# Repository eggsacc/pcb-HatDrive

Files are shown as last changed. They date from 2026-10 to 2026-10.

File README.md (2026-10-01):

# BLDC Hat






A four-layer BLDC motor driver hat built around the TI DRV8316C for the [STM32F405 development module](https://github.com/eggsacc/stm32f405-module). It is intended for six-PWM motor control and field-oriented control experiments.

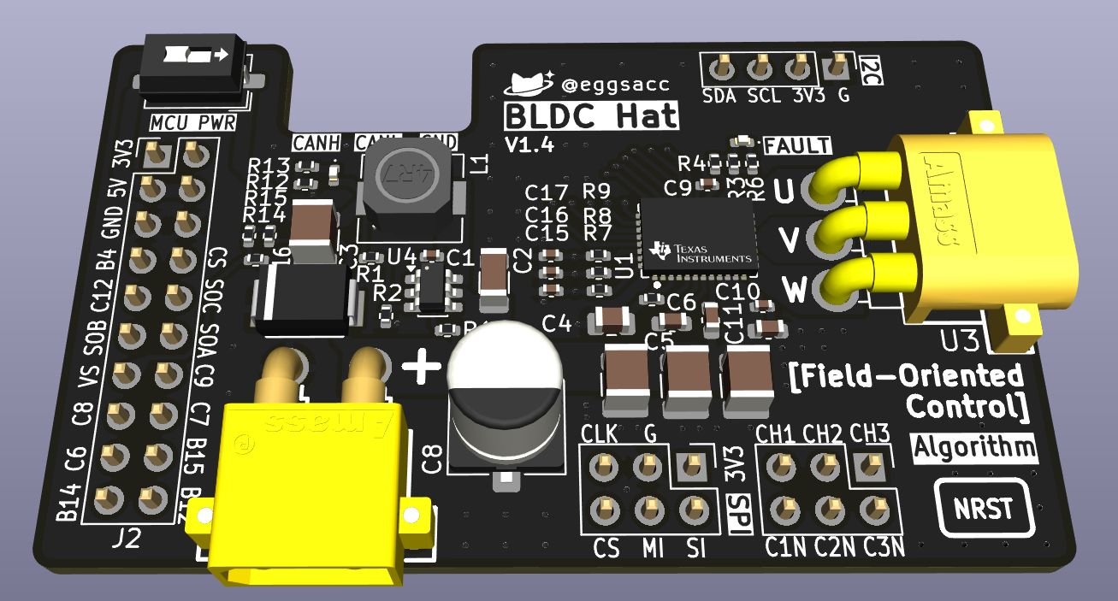
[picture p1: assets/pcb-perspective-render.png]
BLDC Hat perspective render


## Hardware

- Three-phase driver with six PWM inputs, three low-side current-sense outputs, SPI configuration/status, and motor-supply voltage sensing.
- Onboard 5 V buck converter with a switch for MCU power, plus power and fault LEDs.
- Four-layer PCB; board revision V1.4.

## Connectors

| Connector | Purpose |
| --- | --- |
| CN1 · XT30 | Motor power input (`VM_IN`) |
| U3 · MR30 | Three motor phases (`U`, `V`, `W`) |
| J2 · 2×10 | Interface to the STM32F405 module |
| J4 · 2×3 | Six PWM inputs (`CH1–3`, `C1N–3N`) |
| J1 · 2×3 | Driver SPI (`CLK`, `CS`, `MI`, `SI`, 3V3, GND) |
| J5 · 1×4 | I²C (`SDA`, `SCL`, 3V3, GND) |
| CN2 · XT30 | Optional motor-power output; marked DNP in the BOM |

With `MCU PWR` on, the hat supplies 5 V to the MCU module. Its [power guidance](https://github.com/eggsacc/stm32f405-module#power) warns against connecting USB and external 5 V at the same time.

## Layout
>L1: Power & signal

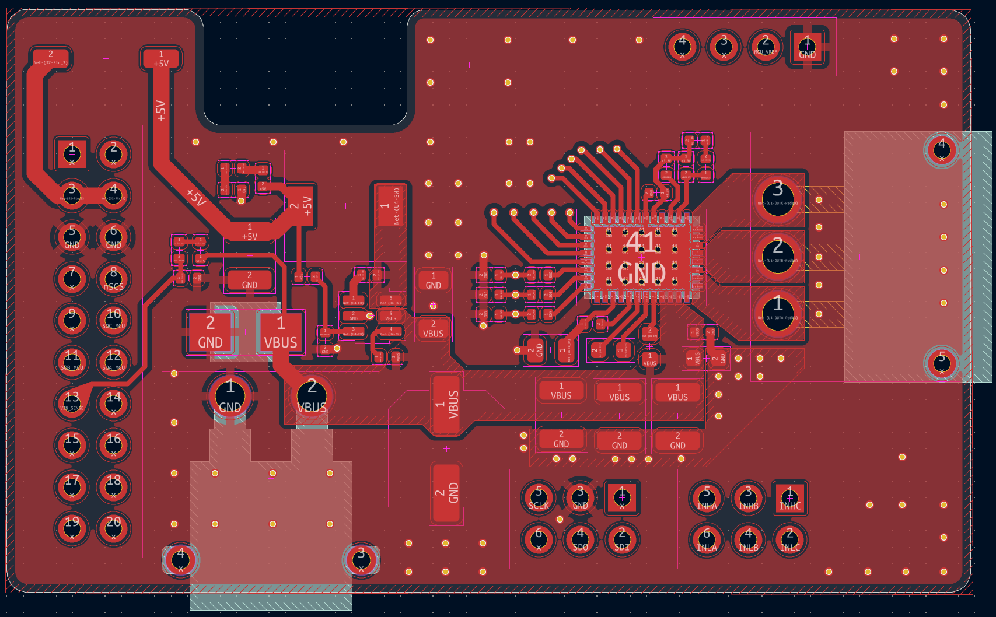
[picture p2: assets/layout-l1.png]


>L2: GND

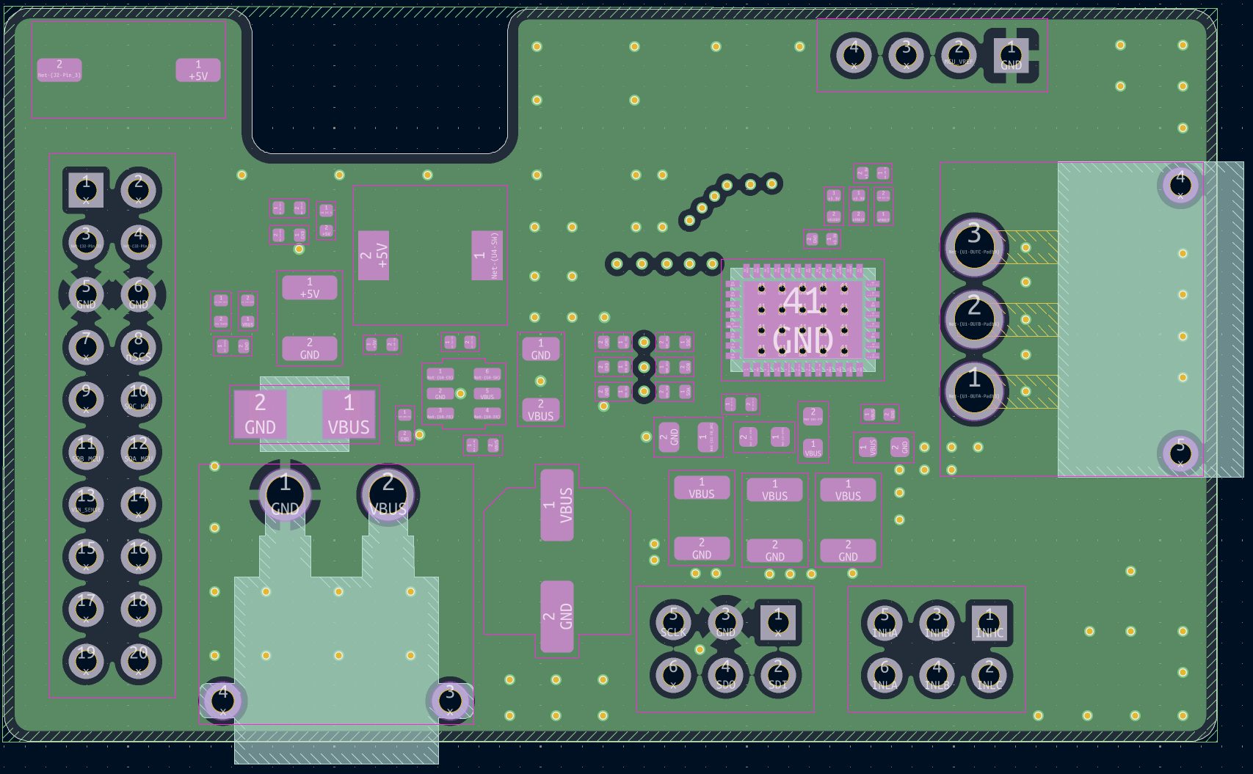
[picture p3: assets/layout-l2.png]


>L3: GND + PWM signal

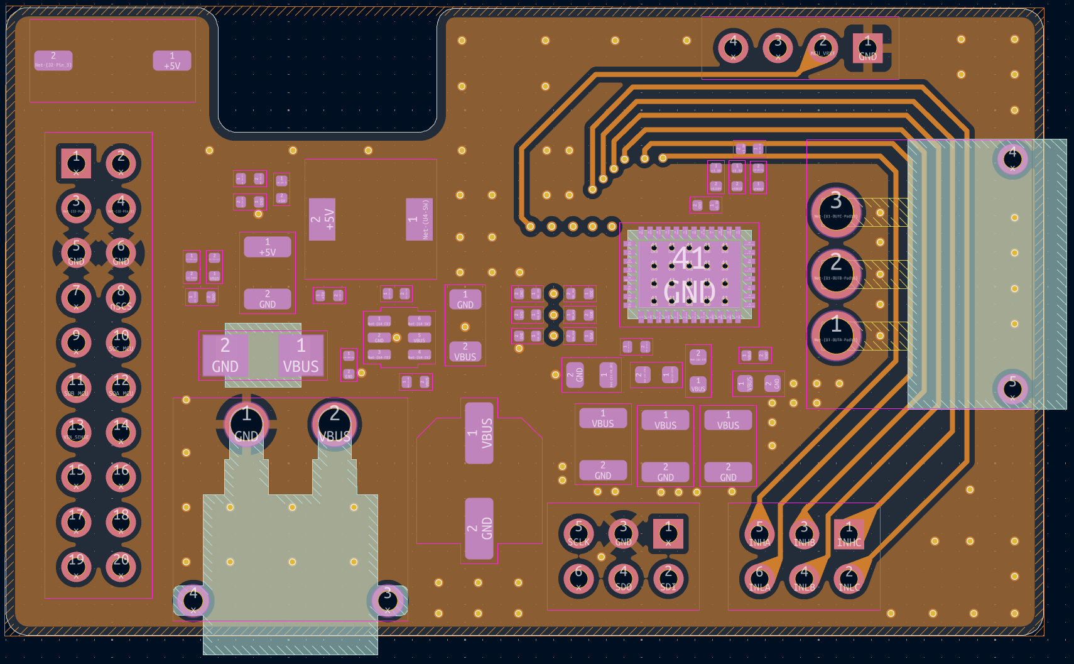
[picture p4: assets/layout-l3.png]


>L4: GND + signal

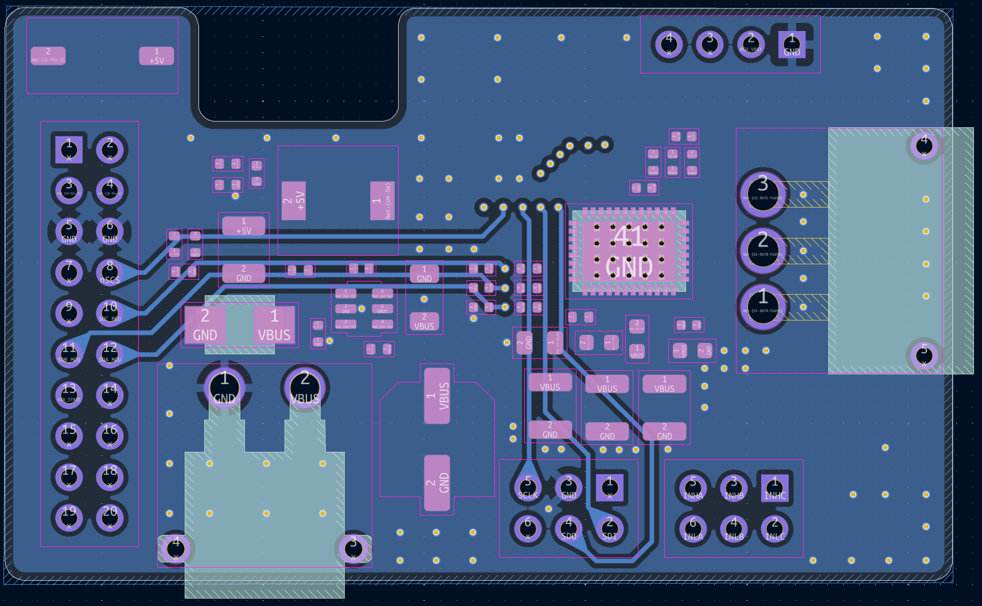
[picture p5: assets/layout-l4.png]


> Silkscreen
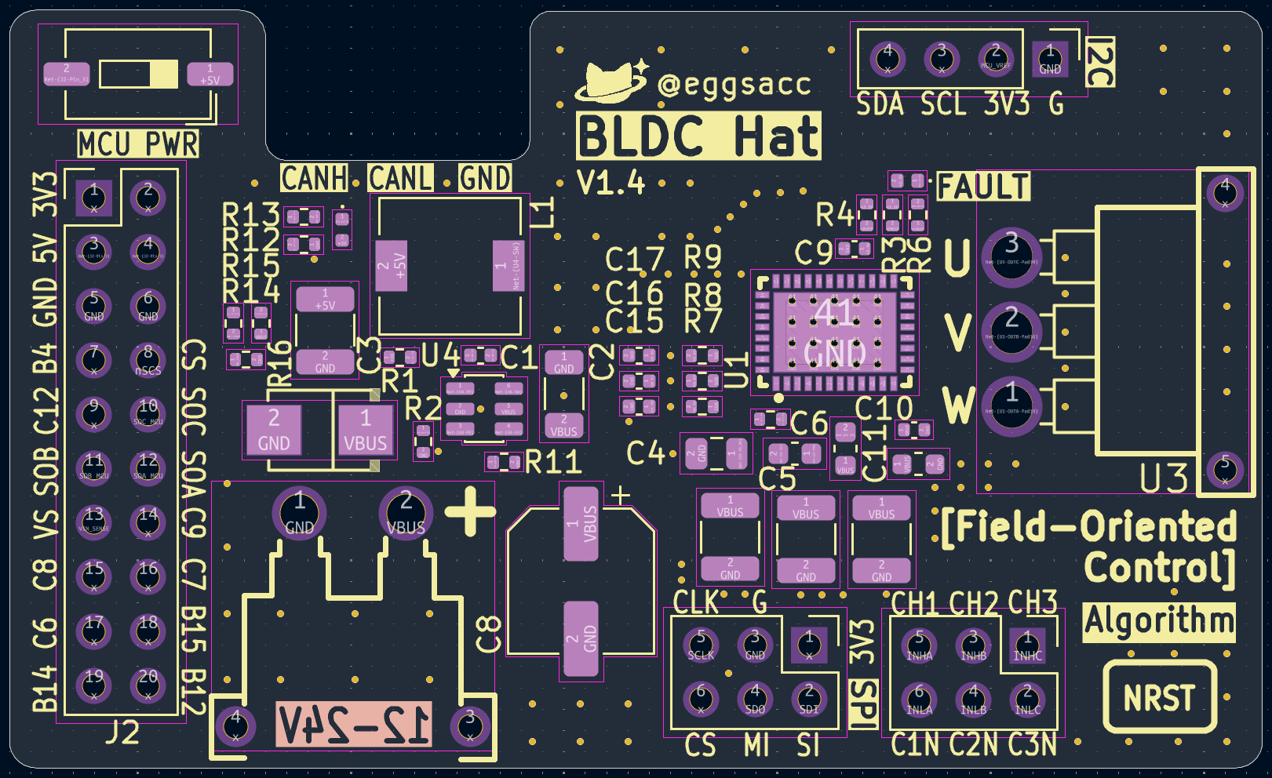
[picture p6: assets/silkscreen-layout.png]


>Combined
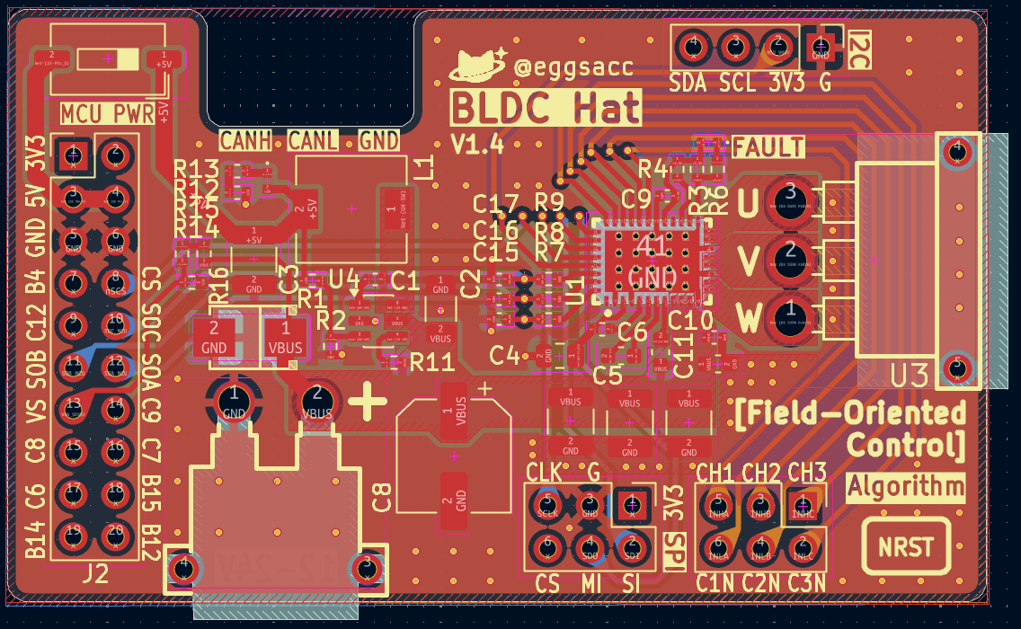
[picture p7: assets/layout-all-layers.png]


The [KiCad project](HatDrive_kicad/) contains the schematic, PCB, and manufacturing files. See the [MCU module README](https://github.com/eggsacc/stm32f405-module) for its pinout.

---

<div align="center">
Designed by <b>@eggsacc</b> · HatDrive V1.4 <br>
Updated 02/10/2026
</div>

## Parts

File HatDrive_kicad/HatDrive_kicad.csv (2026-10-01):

Reference | Qty | Value | DNP | Footprint | Purchased
C1,C10,C11,C12 | 4 | 100n |  | Capacitor_SMD:C_0402_1005Metric | TRUE
C2 | 1 | 2u2 |  | Capacitor_SMD:C_1206_3216Metric | TRUE
C3 | 1 | 22u |  | Capacitor_SMD:C_1210_3225Metric | TRUE
C4 | 1 | 22u |  | Capacitor_SMD:C_0805_2012Metric | TRUE
C5 | 1 | 47n |  | Capacitor_SMD:C_0603_1608Metric | TRUE
C6 | 1 | 1u |  | Capacitor_SMD:C_0603_1608Metric | TRUE
C8 | 1 | 47u |  | Capacitor_SMD:CP_Elec_6.3x7.7 | TRUE
C9 | 1 | 1u |  | Capacitor_SMD:C_0402_1005Metric | TRUE
C15,C16,C17 | 3 | 1n |  | Capacitor_SMD:C_0402_1005Metric | TRUE
C18,C19,C20 | 3 | 10u |  | Capacitor_SMD:C_1210_3225Metric | TRUE
CN1 | 1 | VM_IN |  | fplib_addon:CONN-TH_XT30PW-M | TRUE
CN2 | 1 | VM_OUT | DNP | fplib_addon:CONN-TH_XT30PW-M | TRUE
D1 | 1 | FAULT_LED |  | LED_SMD:LED_0402_1005Metric | TRUE
D2 | 1 | MCU_PWR_LED |  | LED_SMD:LED_0402_1005Metric | TRUE
D3 | 1 | SMBJ28AQ |  | fplib_addon:SMB_L4.3-W3.6-LS5.3-RD | TRUE
J1 | 1 | SPI |  | Connector_PinHeader_2.54mm:PinHeader_2x03_P2.54mm_Vertical | TRUE
J2 | 1 | Breakout header |  | Connector_PinHeader_2.54mm:PinHeader_2x10_P2.54mm_Vertical | TRUE
J4 | 1 | PWM |  | Connector_PinHeader_2.54mm:PinHeader_2x03_P2.54mm_Vertical | TRUE
J5 | 1 | I2C |  | Connector_PinHeader_2.54mm:PinHeader_1x04_P2.54mm_Vertical | TRUE
L1 | 1 | 33u |  | Inductor_SMD:L_6.3x6.3_H3 | TRUE
R1 | 1 | 118k |  | Resistor_SMD:R_0402_1005Metric | TRUE
R2,R14,R15 | 3 | 22k1 |  | Resistor_SMD:R_0402_1005Metric | TRUE
R3,R4,R5,R7,R8,R9,R11 | 7 | 10k |  | Resistor_SMD:R_0402_1005Metric | TRUE
R6,R12,R13 | 3 | 470 |  | Resistor_SMD:R_0402_1005Metric | TRUE
R10 | 1 | 22 |  | Resistor_SMD:R_0402_1005Metric | TRUE
R16 | 1 | 5k1 |  | Resistor_SMD:R_0402_1005Metric | TRUE
SW1 | 1 | MCU_POWER |  | Button_Switch_SMD:SW_DIP_SPSTx01_Slide_6.7x4.1mm_W6.73mm_P2.54mm_LowProfile_JPin | TRUE
U1 | 1 | DRV8316CRRGFR |  | fplib_addon:DRV8316CR | TRUE
U3 | 1 | Phase out |  | fplib_addon:CONN-TH_MR30PW-M30-G-Y | TRUE
U4 | 1 | LMR51610XDBVR |  | Package_TO_SOT_SMD:SOT-23-6 | TRUE

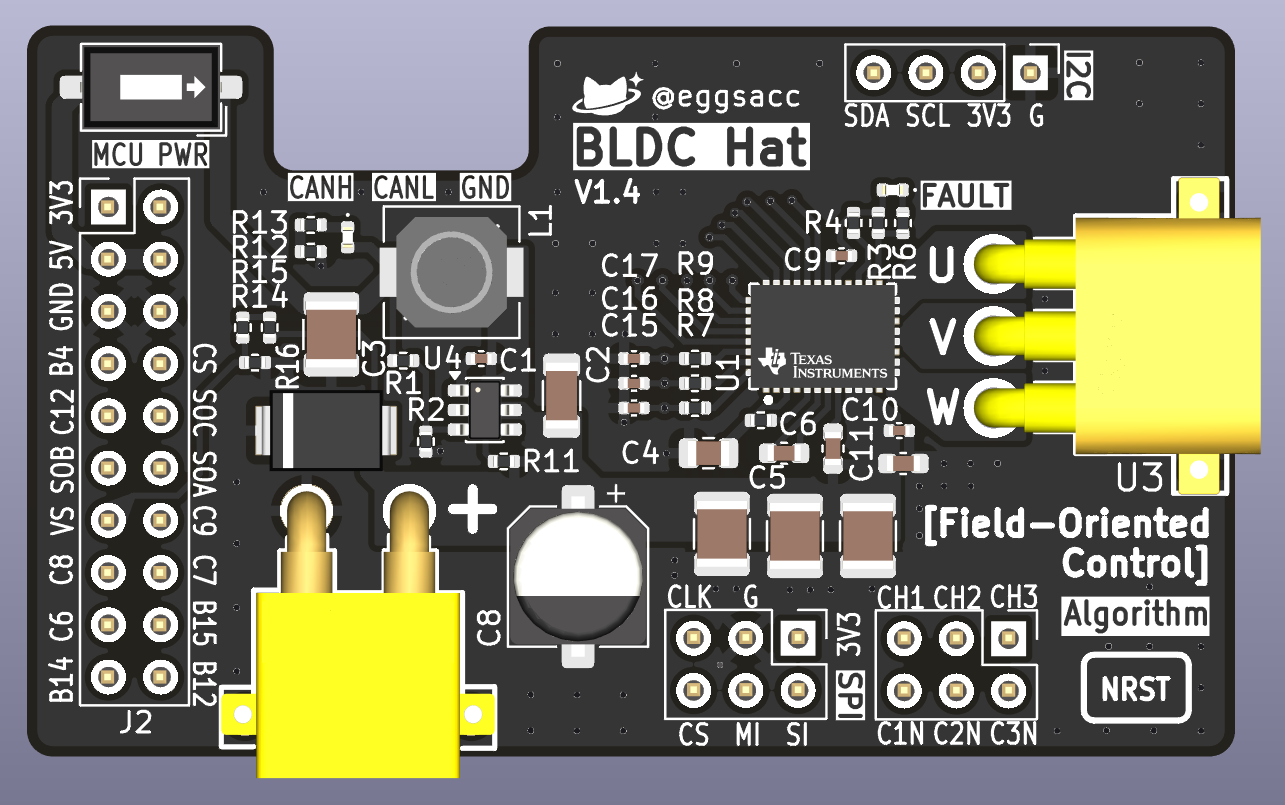
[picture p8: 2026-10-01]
assets/pcb-ortho-all-components.png

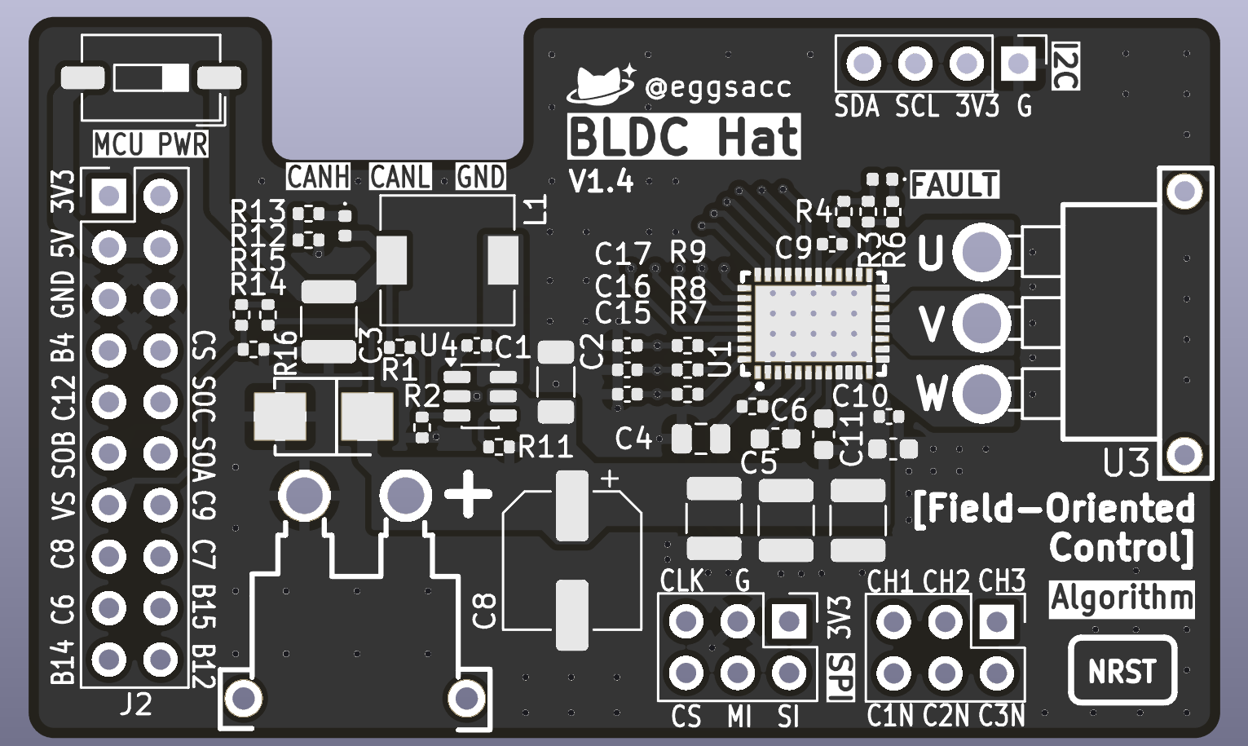
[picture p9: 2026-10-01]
assets/pcb-ortho-no-components.png

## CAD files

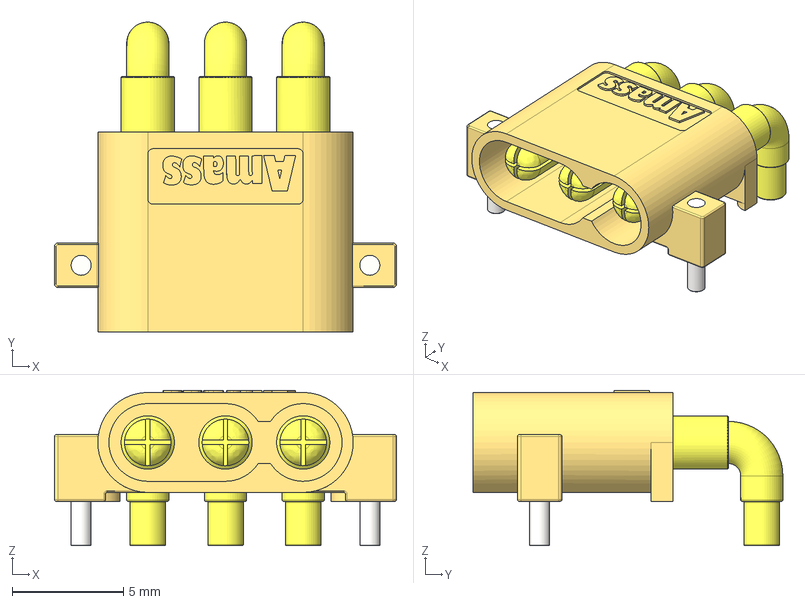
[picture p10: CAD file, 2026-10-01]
HatDrive_kicad/3d-models/MR30PW-M v2.step
15.4 x 13.9 x 7.00 mm
PCB Pins
Pin 2 x 3

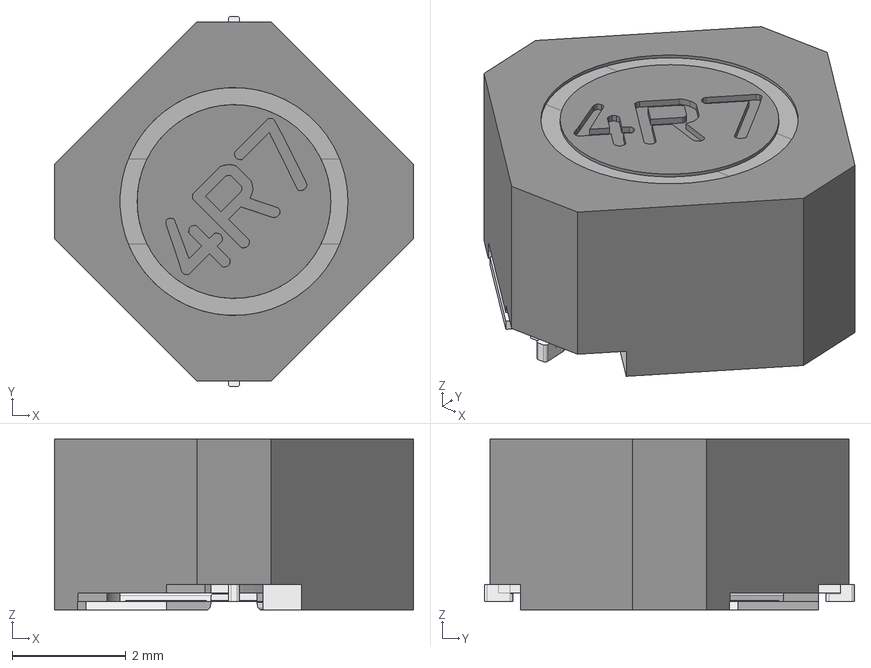
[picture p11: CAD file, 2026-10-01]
HatDrive_kicad/3d-models/Inductor_63.step
6.30 x 6.50 x 3.00 mm
Protection
Inner_Pins
Inductor_Core
Pins
Inductor_Case

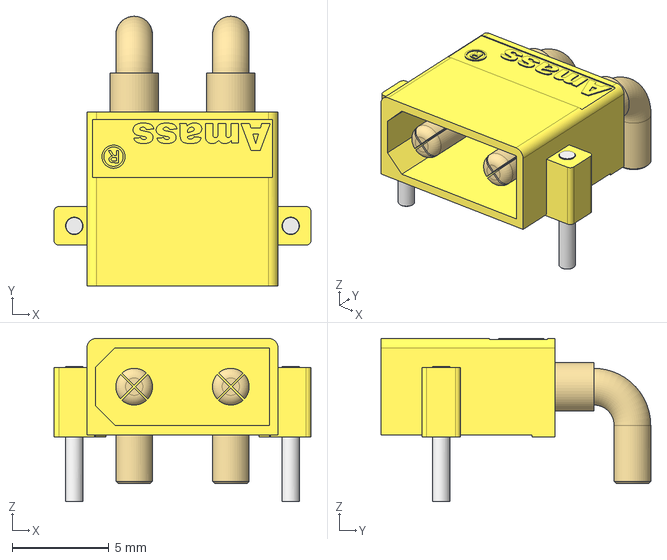
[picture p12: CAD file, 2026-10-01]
HatDrive_kicad/3d-models/Amass_XT30PW-M_pcb solder.stp
13.3 x 13.9 x 8.45 mm

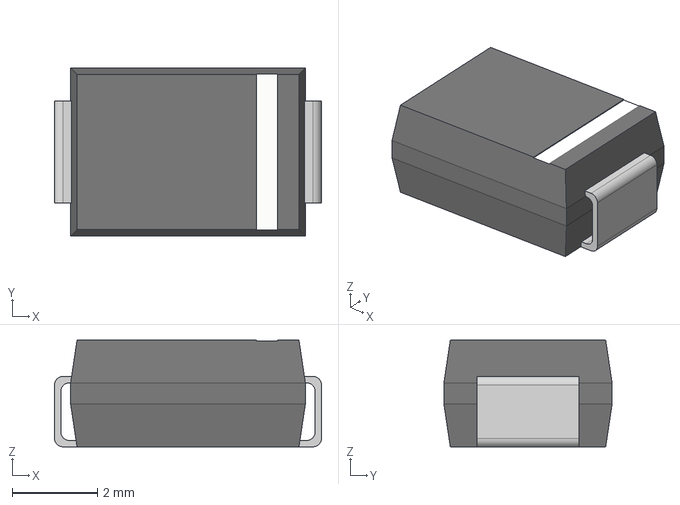
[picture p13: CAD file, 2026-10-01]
HatDrive_kicad/3d-models/smbj-28a.step
6.25 x 3.94 x 2.50 mm

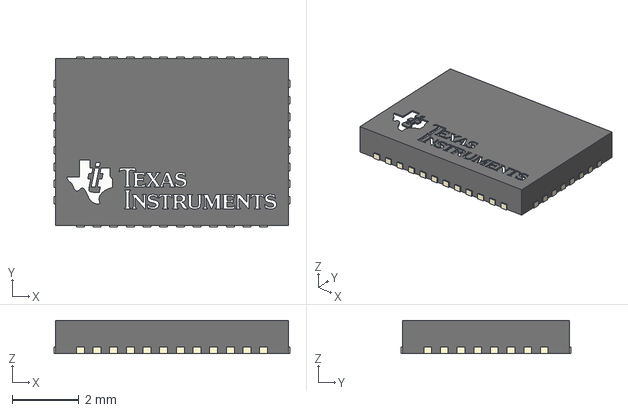
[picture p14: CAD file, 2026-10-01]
HatDrive_kicad/3d-models/VQFN40p-7x5-TI.step
7.08 x 5.09 x 1.00 mm

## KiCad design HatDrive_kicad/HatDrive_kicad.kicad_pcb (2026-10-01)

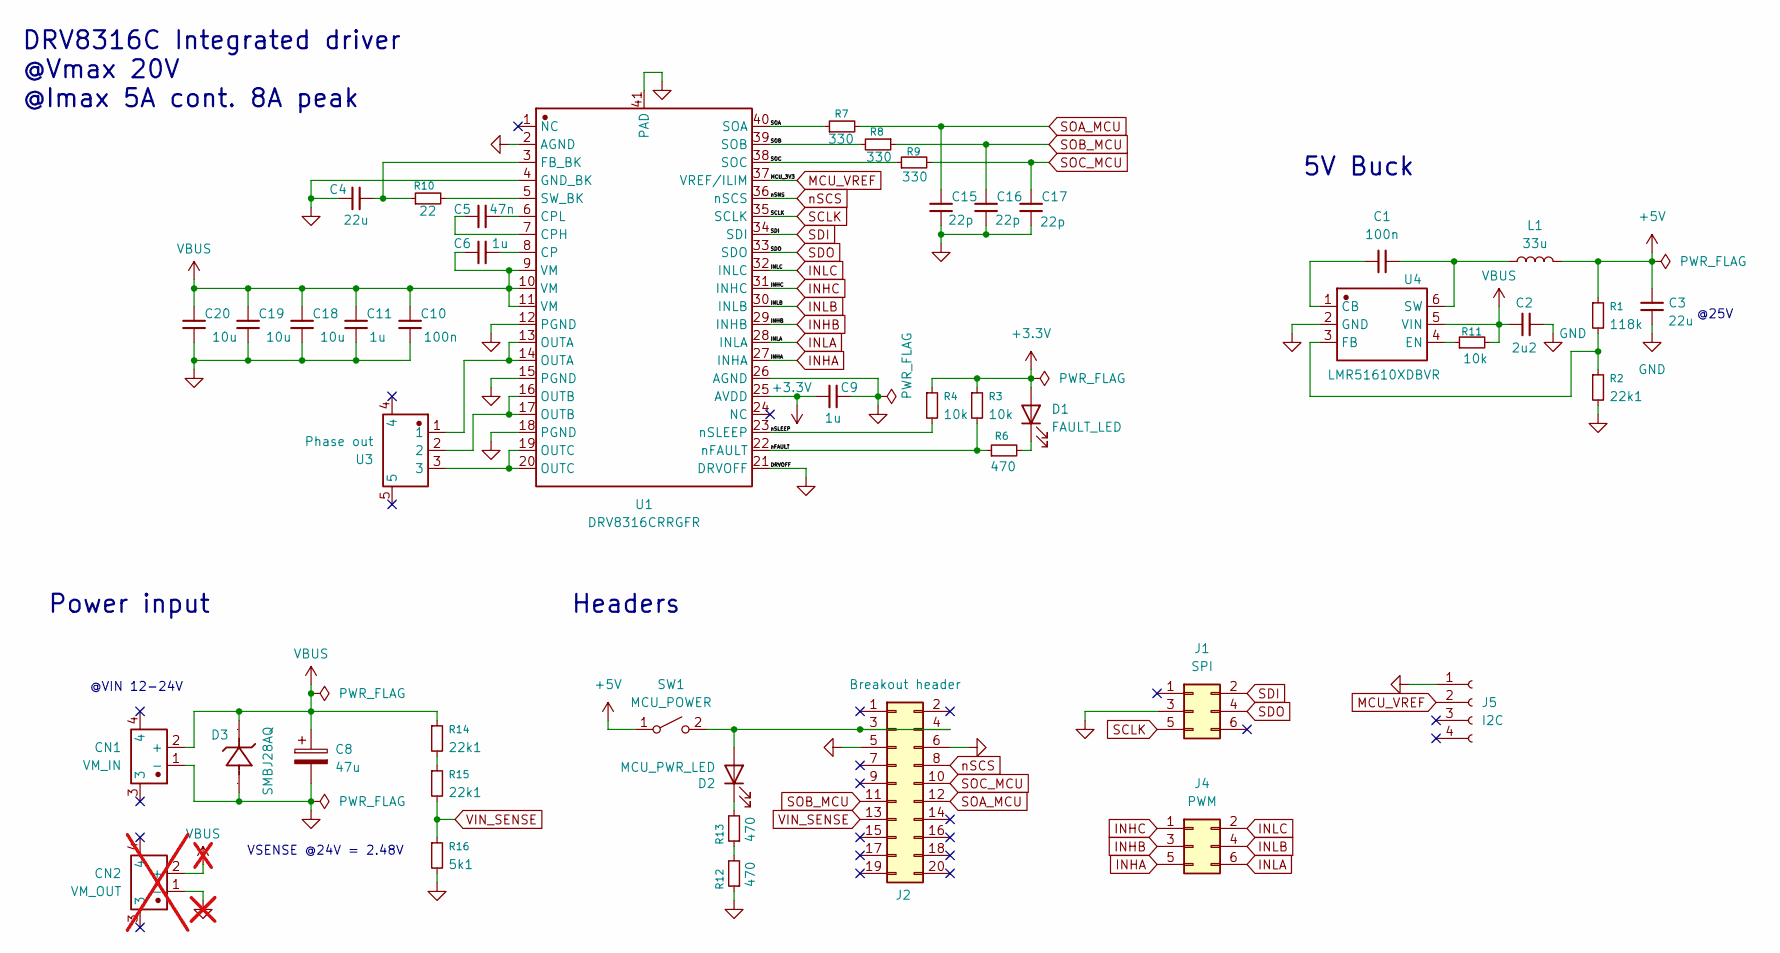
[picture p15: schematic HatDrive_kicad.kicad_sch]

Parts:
C1, C10: 100n; C_0402_1005Metric
C2: 2u2; C_1206_3216Metric
C3: 22u; C_1210_3225Metric
C4: 22u; C_0805_2012Metric
C5: 47n; C_0603_1608Metric
C6, C11: 1u; C_0603_1608Metric
C8: 47u; CP_Elec_6.3x7.7
C9: 1u; C_0402_1005Metric
C15, C16, C17: 22p; C_0402_1005Metric
C18, C19, C20: 10u; C_1210_3225Metric
CN1: VM_IN; CONN-TH_XT30PW-M; Manufacturer Part XT30PW-M
CN2: VM_OUT; CONN-TH_XT30PW-M; Manufacturer Part XT30PW-M; not fitted
D1: FAULT_LED; LED_0402_1005Metric
D2: MCU_PWR_LED; LED_0402_1005Metric
D3: SMBJ28AQ; SMB_L4.3-W3.6-LS5.3-RD; Manufacturer Part SMBJ28AQ
J1: SPI; PinHeader_2x03_P2.54mm_Vertical
J2: Breakout header; PinHeader_2x10_P2.54mm_Vertical
J4: PWM; PinHeader_2x03_P2.54mm_Vertical
J5: I2C; PinHeader_1x04_P2.54mm_Vertical
L1: 33u; L_6.3x6.3_H3
R1: 118k; R_0402_1005Metric
R2, R14, R15: 22k1; R_0402_1005Metric
R3, R4, R11: 10k; R_0402_1005Metric
R6, R12, R13: 470; R_0402_1005Metric
R7, R8, R9: 330; R_0402_1005Metric
R10: 22; R_0402_1005Metric
R16: 5k1; R_0402_1005Metric
SW1: MCU_POWER; SW_DIP_SPSTx01_Slide_6.7x4.1mm_W6.73mm_P2.54mm_LowProfile_J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
U1: DRV8316CRRGFR; DRV8316CR; Manufacturer Part DRV8316CRRGFR
U3: Phase out; CONN-TH_MR30PW-M30-G-Y; Manufacturer Part MR30PW-M30.G.Y
U4: LMR51610XDBVR; SOT-23-6; Manufacturer Part LMR51610XDBVR

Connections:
+3.3V: C9.1, D1.2 (A), R3.1, R4.1, U1.25 (AVDD)
/SOA: R7.1, U1.40 (SOA)
/SOB: R8.2, U1.39 (SOB)
/SOC: R9.1, U1.38 (SOC)
/nFAULT: R3.2, R6.1, U1.22 (nFAULT)
/nSLEEP: R4.2, U1.23 (nSLEEP)
GND: C2.1, C3.2, C4.2, C8.2, C9.2, C10.2, C11.2, C15.2, C16.2, C17.2, C18.2, C19.2, C20.2, CN1.1 (-), CN2.1 (-), D3.2 (A), J1.3, J2.5, J2.6, J5.1, R2.2, R12.1, R16.2, U1.2 (AGND), U1.4 (GND_BK), U1.12 (PGND), U1.15 (PGND), U1.18 (PGND), U1.21 (DRVOFF), U1.26 (AGND), U1.41 (PAD), U4.2 (GND)
INHA: J4.5, U1.27 (INHA)
INHB: J4.3, U1.29 (INHB)
INHC: J4.1, U1.31 (INHC)
INLA: J4.6, U1.28 (INLA)
INLB: J4.4, U1.30 (INLB)
INLC: J4.2, U1.32 (INLC)
MCU_VREF: J5.2, U1.37 (VREF/ILIM)
unnamed: D1.1 (K), R6.2
unnamed: D2.1 (K), R13.2
unnamed: R12.2, R13.1
unnamed: R14.2, R15.1
unnamed: C6.2, U1.8 (CP)
unnamed: C5.1, U1.7 (CPH)
unnamed: C5.2, U1.6 (CPL)
unnamed: C4.1, R10.1, U1.3 (FB_BK)
unnamed: U1.13 (OUTA), U1.14 (OUTA), U3.1
unnamed: U1.16 (OUTB), U1.17 (OUTB), U3.2
unnamed: U1.19 (OUTC), U1.20 (OUTC), U3.3
unnamed: R10.2, U1.5 (SW_BK)
unnamed: C1.1, U4.1 (CB)
unnamed: R11.1, U4.4 (EN)
unnamed: R1.2, R2.1, U4.3 (FB)
unnamed: C1.2, L1.1, U4.6 (SW)
SCLK: J1.5, U1.35 (SCLK)
SDI: J1.2, U1.34 (SDI)
SDO: J1.4, U1.33 (SDO)
SOA_MCU: C15.1, J2.12, R7.2
SOB_MCU: C16.1, J2.11, R8.1
SOC_MCU: C17.1, J2.10, R9.2
VBUS: C2.2, C6.1, C8.1, C10.1, C11.1, C18.1, C19.1, C20.1, CN1.2 (+), CN2.2 (+), D3.1 (C), R11.2, R14.1, U1.9 (VM), U1.10 (VM), U1.11 (VM), U4.5 (VIN)
VIN_SENSE: J2.13, R15.2, R16.1
nSCS: J2.8, U1.36 (nSCS)

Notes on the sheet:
DRV8316C Integrated driver @Vmax 20V @Imax 5A cont. 8A peak
VSENSE @24V = 2.48V
Power input
5V Buck
@VIN 12-24V
Headers
@25V

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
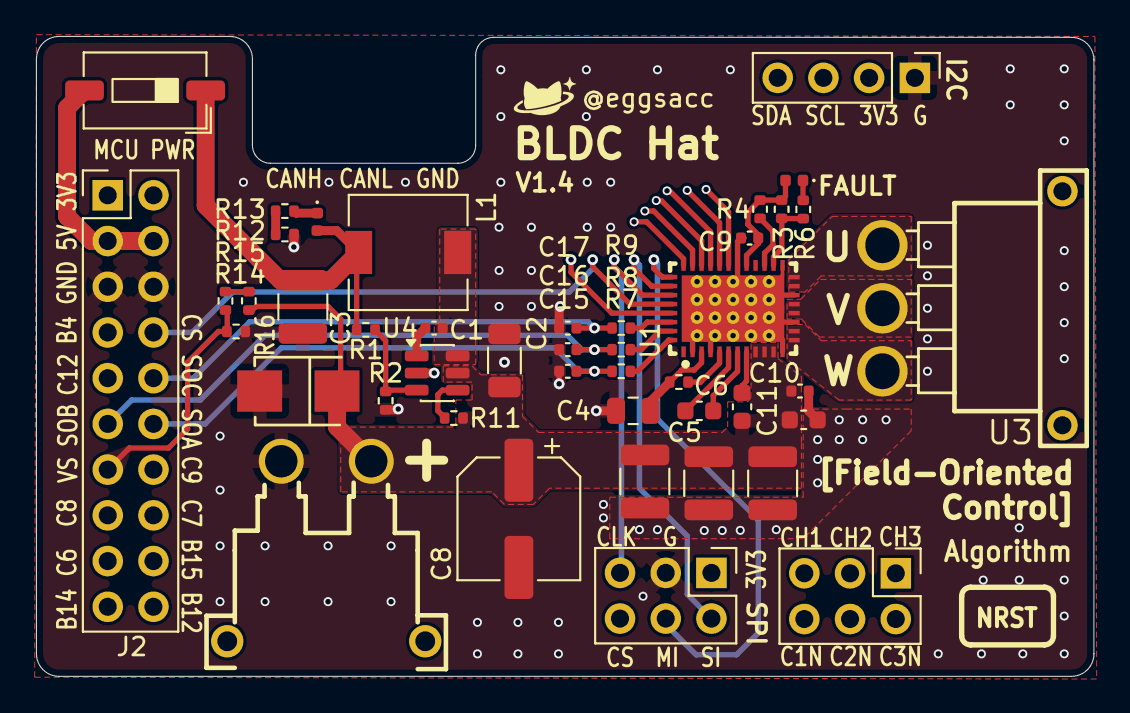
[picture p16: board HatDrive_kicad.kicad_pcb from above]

Board: 4 copper layers, 58.8 x 35.5 mm, 44 parts (0 on the bottom side), 41 nets.
